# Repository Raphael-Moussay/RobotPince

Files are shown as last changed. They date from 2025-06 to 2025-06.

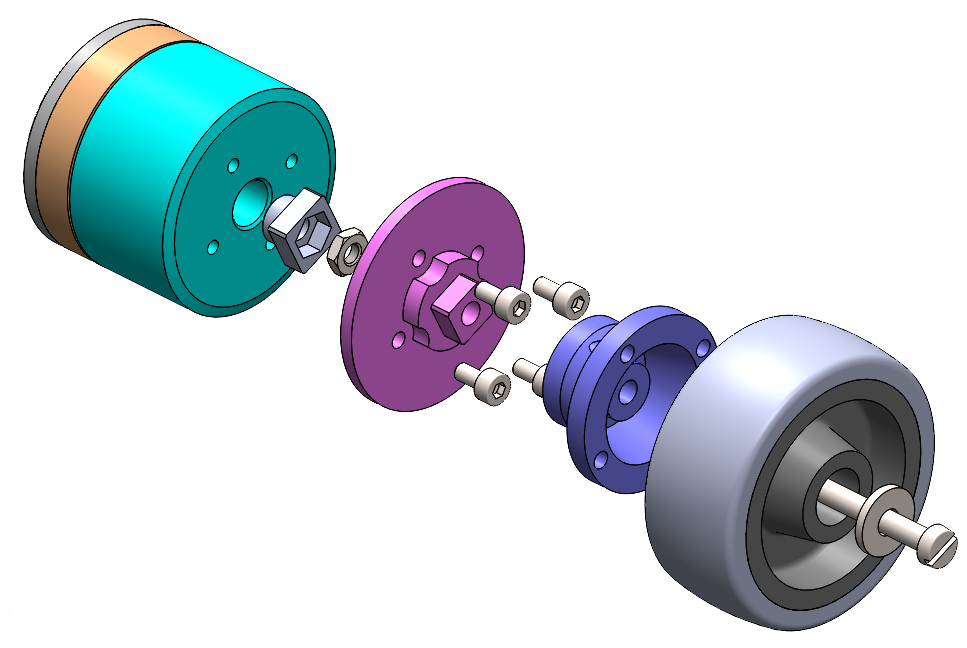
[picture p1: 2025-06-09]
Robot Sous Assemblé/00 composants fournis/moteur MS4015 et roue/montage des roues.png

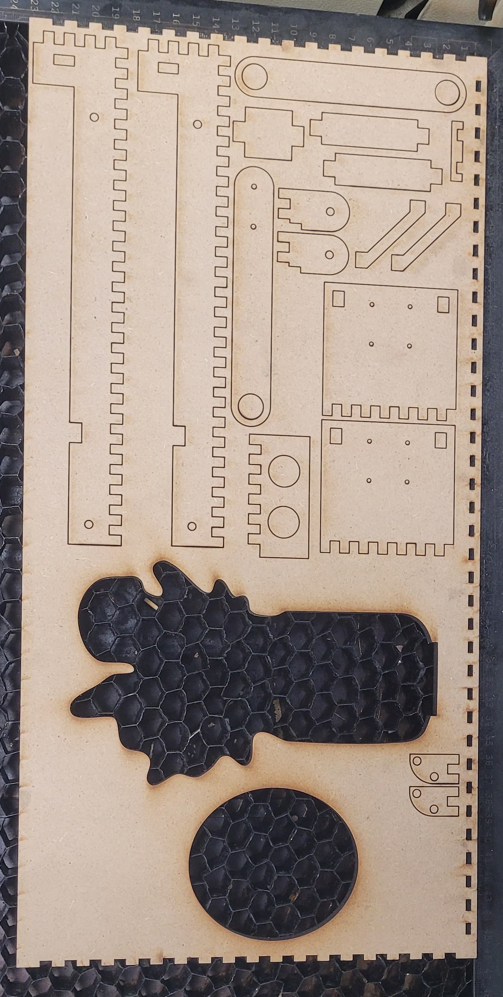
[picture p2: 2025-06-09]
Image découpe laser.jpg

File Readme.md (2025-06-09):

# ROBOPINCEBOT

https://wiki.fablab.sorbonne-universite.fr/BookStack/books/projets-due-2024-2025/page/projet-rob3-gaelle-raphael-sofiane-jean-yves-harold-stanislas

## Description

**ROBOPINCEBOT** est un robot mobile autonome développé dans le cadre du projet de robotique de 3e année à Polytech Sorbonne, spécialité Robotique (février – juin 2025). Le robot est conçu pour localiser, saisir, transporter et déposer un objet dans une arène délimitée à l’aide d’un bras articulé et d’une pince motorisée.

Ce projet a été réalisé au Fablab de Sorbonne Université et mobilise des compétences en mécatronique : conception mécanique (modélisation, usinage), électronique embarquée, programmation sur Arduino et mise en œuvre de capteurs.

## Objectifs

- Concevoir et fabriquer un robot mobile autonome.
- Développer un algorithme de navigation simple par capteurs ultrason.
- Implémenter un système de préhension d’objet via un bras motorisé.
- Réaliser une démonstration fonctionnelle dans un environnement contraint.

## Équipe

| Nom | Email |
|---|---|
| Sofiane BENRABIA | s.benavron@gmail.com |
| Gaelle MARDIKIAN | gaellemardikian29@gmail.com |
| Raphaël MOUSSAY | raphael.moussay@gmail.com |
| Jean ORIEUX | jeanorx@gmail.com |
| Stanislas PINART | stanislas.pinart@gmail.com |
| Yves-Harold VALCIUS  | yvesharoldvalcius11@gmail.com |

## Matériel utilisé

- Carte Arduino UNO
- 3 moteurs MS4015 avec encodeurs
- Bus CAN (MCP2515)
- 2 capteurs à ultrasons HC-SR04
- 1 servomoteur pour la pince
- 1 bouton poussoir
- 2 roues + 1 roue folle
- Batterie
- 2 LabDecks
- Pièces usinées en MDF (laser) via fichiers DXF SolidWorks

## Fonctionnalités

- Déplacement du robot à l’aide de moteurs contrôlés par bus CAN
- Odométrie de position et d’angle
- Détection d’obstacles avec ultrasons (horizontal et vertical)
- Préhension et dépose d’un objet avec une pince articulée
- Démarrage d’une séquence automatisée via bouton poussoir

## Installation

1. **Branchements** : suivre le schéma de câblage dans `https://wiki.fablab.sorbonne-universite.fr/BookStack/books/projets-due-2024-2025/page/projet-rob3-gaelle-raphael-sofiane-jean-yves-harold-stanislas`.
2. **Chargement du code** : ouvrir `Code_Pincebot_final.ino` dans l’IDE Arduino et téléverser sur la carte.
3. **Alimentation** : connecter la batterie.
4. **Démarrage** : appuyer sur le bouton poussoir pour lancer la séquence automatique.

## Dépendances logicielles (Arduino)

- `Servo.h` – contrôle du servomoteur
- `SPI.h` – communication SPI
- `mcp_can.h` / `mcp2515_can.h` – gestion du module CAN MCP2515

## Avancement et journal de bord

Le projet s’est déroulé sur plusieurs mois selon une approche itérative : prototypage, test, ajustement mécanique, implémentation électronique, puis intégration finale.

Les activités hebdomadaires détaillées sont disponibles dans le fichier `Gantt.pdf`.

## Solutions techniques

- **Mobilité** : deux roues arrière motorisées, une roue folle avant
- **Préhension** : pince fixée sur un bras articulé
- **Capteurs** : ultrasons pour éviter les obstacles et mesurer la hauteur de l’objet
- **Commande** : via Arduino et bus CAN, odométrie implémentée par retour encodeur

## Problèmes rencontrés

- Imprécisions des capteurs ultrasons à courte distance
- Stabilité du bras (ajout d’un élastique pour équilibrer le poids)
- Calcul de la position cible pour la dépose (approximation en fonction de l’objet)

## Licence

Ce projet est réalisé à but pédagogique, dans le cadre du cursus ingénieur de Polytech Sorbonne. Toute réutilisation doit être mentionnée comme projet étudiant.

---

*Pour toute question, se référer à la documentation ou contacter l’un des membres de l’équipe.*

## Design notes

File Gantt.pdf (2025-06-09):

GANTT CHART ROB3 Project | Le sujet du projet | Wiki FablabSU (https://wiki.fablab.sorbonne-universite.fr/BookStack/books/projets-due-2024-2025/page/le-sujet-du-projet)
PROJECT TITLE | GANTT CHART ROB3 Project | COMPANY NAME | Les ROBBBB
PROJECT PARTICIPANT | MOUSSAY Raphaël, , ORIEUX Jean, BENRABIA Sofiane, PINART MENUGE Stanislas, MARDIKIAN Gaelle,VALCIUS Yves Harold | DATE | 13/2/2025
Advancement | #REF! | #REF!
TASK TITLE | TASK OWNER | PCT OF TASK COMPLETE | 13/02/2025 | 06/03/2025 | 20/03/2025 | 3/4/2025 | 15/05/2024 | 04/06/2024 DESCRIPTION
CAO (Responsable : Raphael) | | 100,00% | | | | Manifestation devant la fac
Test Découpe laser | Liason entre les plaques, trou pour
les roulements | Raphaël | 100,00%
Modelisation sur Solidworks | Ensemble des pièces | Raphaël | 100,00%
Création des fichiers DXF | Fichier dxf pour chaque pièce à
couper | Raphaël | 100,00%
Découpe laser | Utilisation de la Trotec Speedy
1000 | Raphaël | 100,00%
Montage Robot | Assemblage des pièces | Jean | 100,00%
Dimensionnement | Mesure et calculs pour le bras de la
pince | Stanislas | 100,00%
Equations | Mouvement pour attraper l'objet
quelque soit sa taille | Sofiane | 100%
Bouton poussoir | Découpe et labdeck | Jean
ELECTRONIQUE (Responsable : Gaelle) | | 100,00%
Cablage moteurs +arduino | Code et branchements | Gaëlle | 100,00%
Branchement moteur et bus CAN | Communication entre pince et
arduino | Gaëlle | 100,00%
fonction de la distance récupérée | Gaëlle | 100,00%
Mise en commun codes moteurs et lidar | Commander les moteurs en
Cablage des lidars | Gaëlle | 100,00%
Recharge des batteries | Jean | 100,00%
INFORMATIQUE (Responsable : Yves Harold) | | 100,00%

Test ultrason + Documentation

Savoir ce que renvoit le detecteur, est-ce possible de détecter une hauteur ? l'angle fait entre un objet le robot ? | Harold | 100,00%
Comment faire la liaison moteur <--> arduino ? La fonction de transfert associé avec les bonnes unités ? La conversion de la consigne/commande ? Commande en vitesse ? | Harold | 100,00%

Test moteur + Documentation

Odométrie | Mesure en distance et angle | Harold | 100,00%
Détection des bornes | Changer la vitesse et l'angle à son
| approche | Gaëlle | 100,00%
Saisir l'objet | Hauteur et distance ? | Gaëlle | 100,00%
Relâcher l'objet | Comment le laisser droit au bon endroit ? | Gaëlle | 100,00%
Avance après la balise | | Stanislas | 100,00%
Bouton poussoir | Code | Raphaël | 100,00%
Assembage des fonctions et code complet | | EVERYBODY | 100,00%
Rapport | Sofiane

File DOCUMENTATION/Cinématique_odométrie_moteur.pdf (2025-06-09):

# Cinématique d'un robot mobile de type unicycle

## 1 Introduction et paramétrage

On qualifiera d'unicyle un robot mobile constitué de deux roues motrices indépendantes situées sur le même essieu et d'une roue folle (non motorisée) assurant la stabilité du robot. En supposant le roulement sans glissement des roues sur le sol :

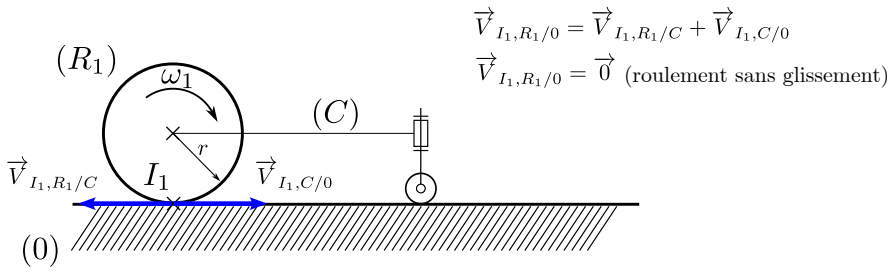
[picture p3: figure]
(roulement sans glissement)
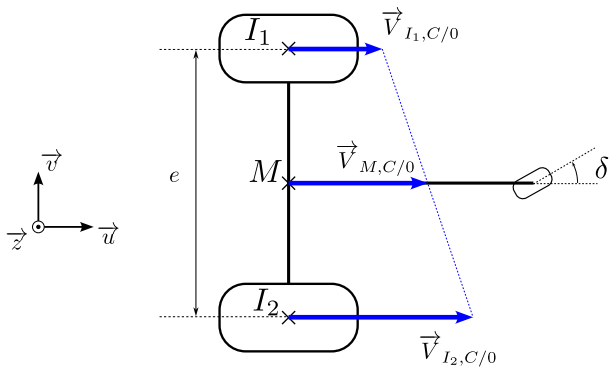
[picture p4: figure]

À tout instant, le centre instantanné de rotation (CIR) du mouvement du chassis par rapport au sol définit le champ des vitesses en rotation. Notons que lorsque les deux moteurs tournent à la même vitesse, le CIR s'éloigne à l'infini et toutes les vitesses sont identiques, c'est une translation. Il est alors possible de déterminer les éléments du torseur cinématique : fVC/Og=(

~
C/0

V~M;C/0 )

M

## 2 Détermination du torseur cinématique du robot en fonction des vitesses angulaires des moteurs

En transportant le torseur respectivement en I1 et I2 : V~

I1;C/0=V~M;C/0+I1M^~

C/0 avec V~
I1;C/0=r!1~u et I1M=¡

e2 ~v

V~

I2;C/0=V~M;C/0+I2M^~

C/0 avec V~
I2;C/0=r!2~u et I2M=

e2 ~v
Par addition : V~

I1;C/0+V~

I2;C/0=2VM;C/0+(I1M+I2M)^~ C/0=2VM;C/0

On obtient : V~M;C/0=

1
2

(V~

I1;C/0+V~
I2;C/0)=

r
2

(!1+!2)~u

1

Par soustraction : V~

I2;C/0¡V~

I1;C/0=I2M^~

C/0¡I1M^~

C/0=e~v^~
C/0
En projection sur ~u : (V~

I2;C/0¡V~

I1;C/0)~u=(e~v^~

C/0)~u=e(~u^~v)~

C/0=e~z~
C/0
On obtient : ~
C/0=

re (!2¡!1)~z

Par commodité, on introduit les notations : V~M;C/0=V~u et ~
C/0=
~z
On peut alors relier les vitesses angulaires des deux roues aux caractéristiques cinématiques du robot (au centre de l'essieu) :

V

=0
@
| r2

r2 ¡

re

re 1
A
!1

!2

forme matricielle qui s'inverse en
!1

!2 =0
@

1
r ¡

e2r 1

r | e2r | 1
A
V

## 3 Répérage et cinématique du robot dans le plan

Pour un repérage du robot dans le plan :

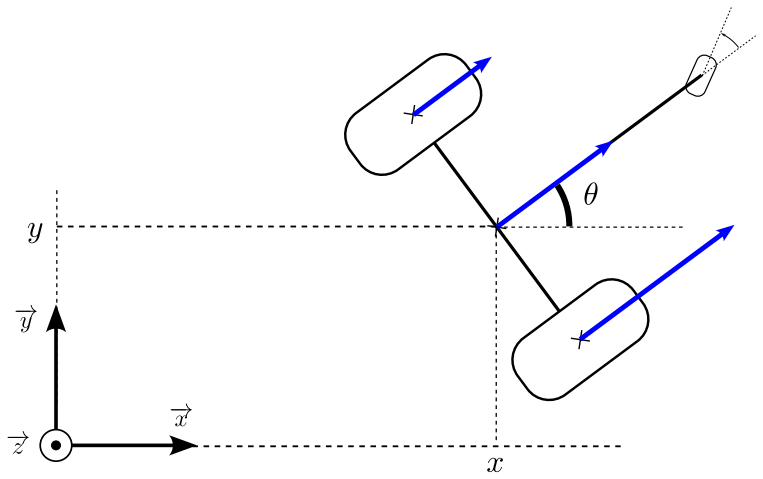
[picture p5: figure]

On définit un vecteur p=0
@

x
y

1
A on peut alors écrire

p_=0
B@

x_y_

_ 1
CA=0
@

V cos
V sin

1

A=0
B
@

r
2

(!1+!2) cos
r
2

(!1+!2)sin
r
e

(!2¡!1)

1
C
A

=0
B
@

r2 cos

r2 cos

r2
sin

r2
sin ¡

re

re 1
C
A
!1

!2

Pour déterminer la vitesse d'un autre point que le centre de l'essieu dans le repère fixe R0, on peut passer par les coordonnées de ce point dans le repère RR au robot. Par exemple, on peut définir un point P tel que MP=a~u. Dans ce cas, la vitesse du point P dans la base mobile est définie par VP /RR=V~u¡a~u^

~z=V~u+a
~v. Le vecteur décrivant les caractéristiques cinématiques au point P dans le repère RR est noté : qR=( V a

)T on cherche q

0=

¡ x_P y_P
_P

T
(dans le repère R0). 2

La vitesse de P dans la base fixe peut alors être déterminée en utilisant la matrice de rotation de la base liée au robot par rapport à la base fixe : R()=0
B@

cos ¡sin 0
sin cos 0
0 | 0 | 1

1
CA

et q

0=R()qR)q

0=0
@

V cos¡a

sin
V sin+a
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
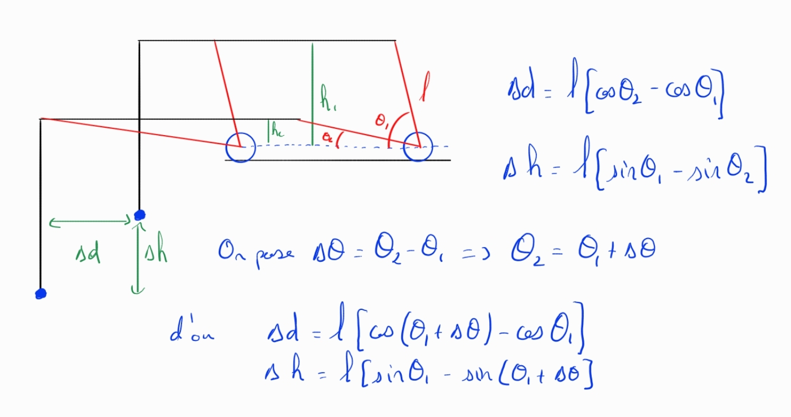
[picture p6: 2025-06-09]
Angle_Distance.jpg

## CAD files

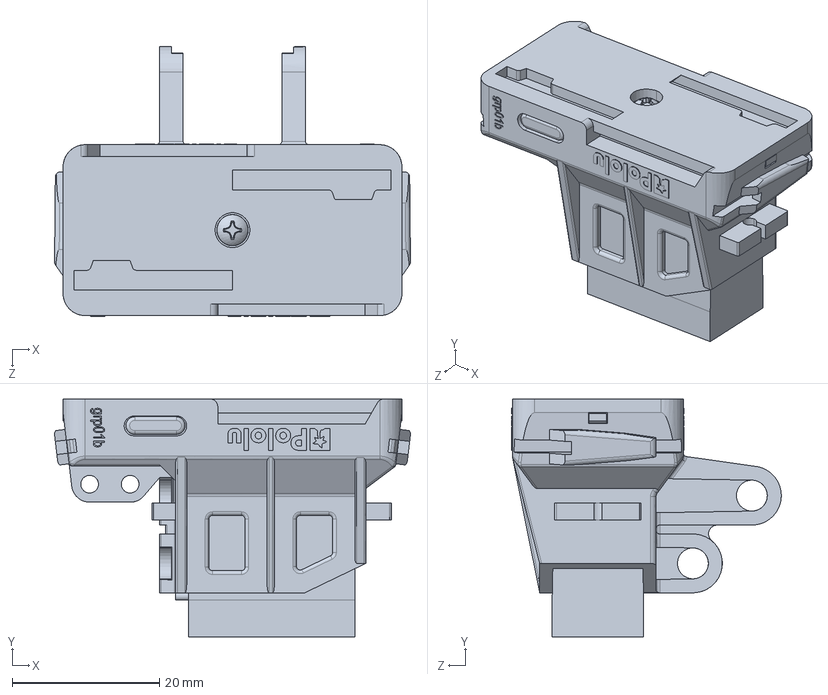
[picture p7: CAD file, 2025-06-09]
Robot Sous Assemblé/00 composants fournis/pince pololu/assembled_gripper_1_1.SLDPRT
48.3 x 32.3 x 36.6 mm

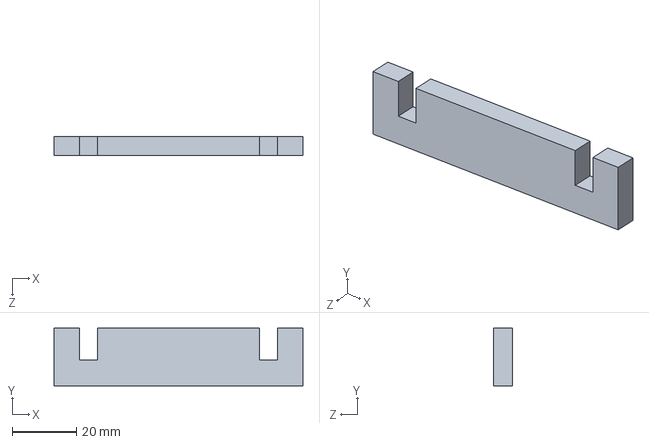
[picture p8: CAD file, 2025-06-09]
Robot Sous Assemblé/Chassis/Maintient ecartement roue arrière.SLDPRT
77.6 x 18.0 x 6.00 mm

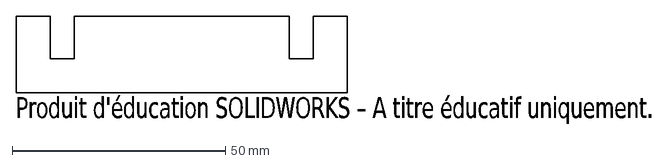
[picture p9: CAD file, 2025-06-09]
Robot Sous Assemblé/DXF/maintient ecartement roue arrière.DXF
Produit d'éducation SOLIDWORKS – A titre éducatif uniquement.

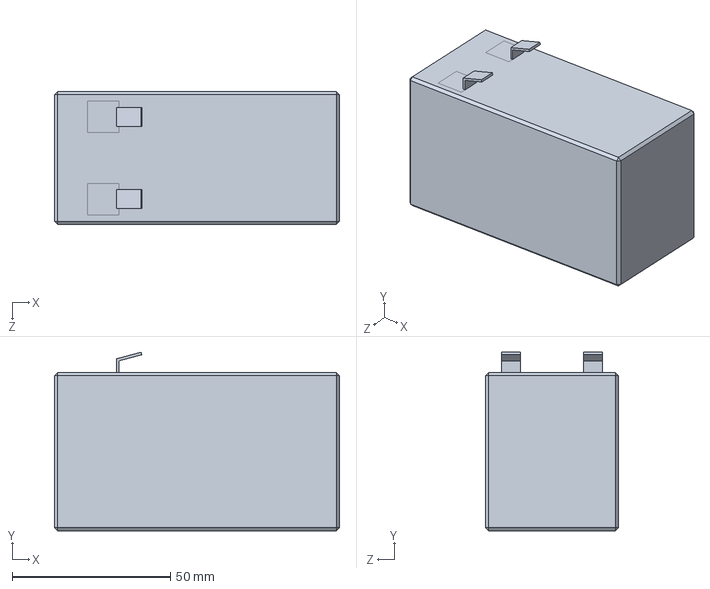
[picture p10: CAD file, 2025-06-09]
Robot Sous Assemblé/00 composants fournis/batterie RS pro 12v/Batterie.SLDPRT
90.0 x 56.4 x 42.0 mm

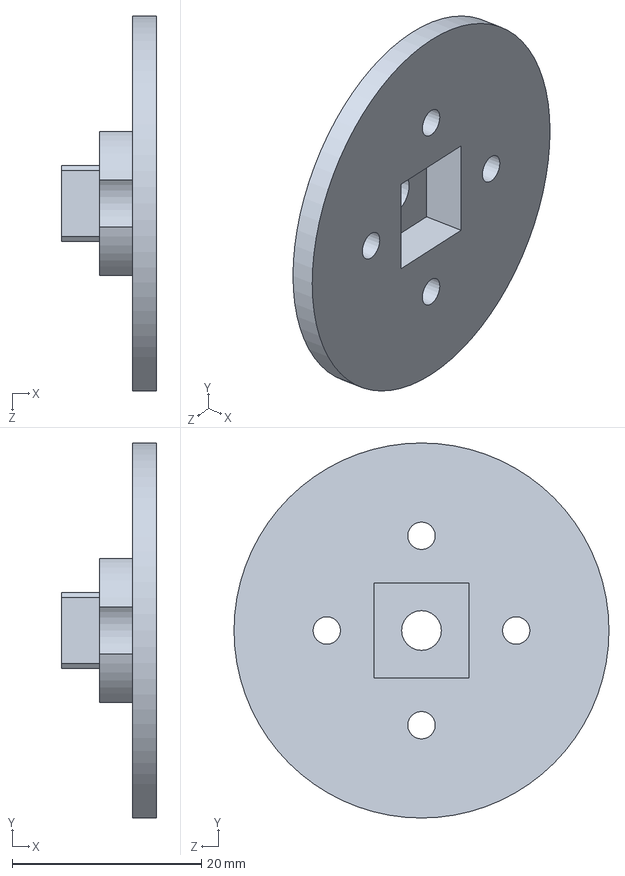
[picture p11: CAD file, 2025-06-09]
Robot Sous Assemblé/00 composants fournis/moteur MS4015 et roue/Entrainement moteur.SLDPRT
10.0 x 39.6 x 39.6 mm

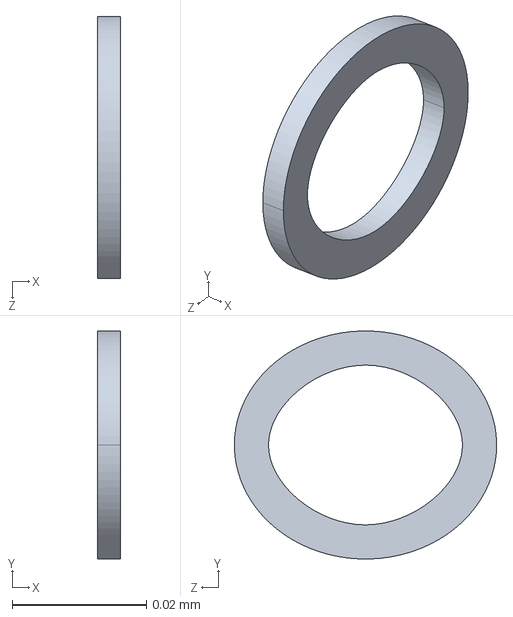
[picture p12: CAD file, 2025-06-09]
Robot Sous Assemblé/00 composants fournis/moteur MS4015/MS4015v21.SLDPRT
0.0034 x 0.034 x 0.0391 mm

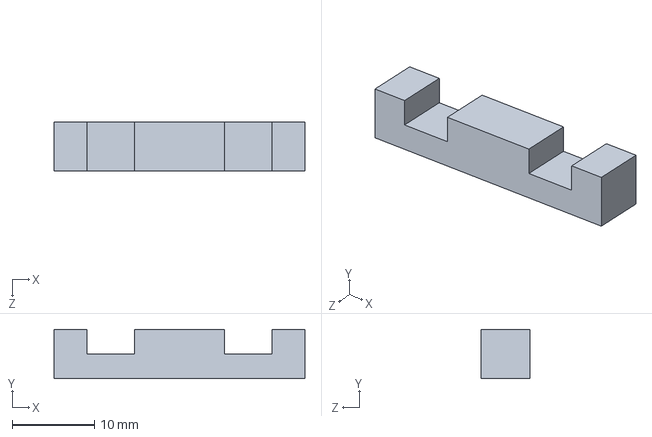
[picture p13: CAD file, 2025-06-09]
Robot Sous Assemblé/Chassis/entretoise Support fourche avant.SLDPRT
30.6 x 6.00 x 6.00 mm

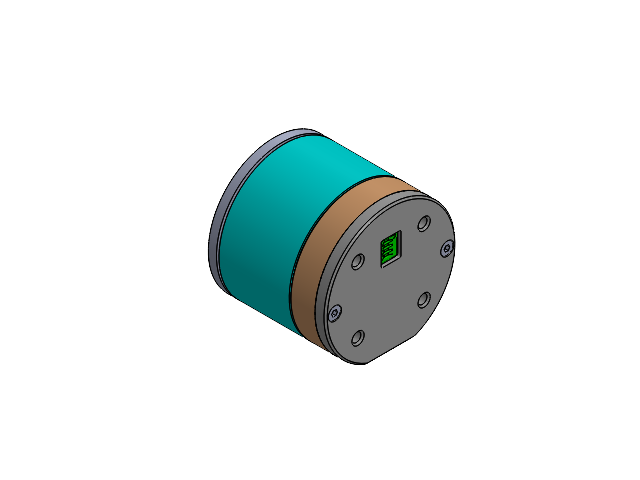
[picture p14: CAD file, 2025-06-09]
Robot Sous Assemblé/00 composants fournis/moteur MS4015 et roue/Moteur équipé.SLDASM
Entrainement moteur
MS4015v21
MS4015v22
MS4015v23
MS4015v24
MS4015v25
MS4015v26
MS4015v27
MS4015v28
MS4015v29
MS4015v210
MS4015v211
MS4015v212
MS4015v213
MS4015v214
MS4015v215
MS4015v216
MS4015v217
MS4015v218
MS4015v219
MS4015v220
MS4015v221
MS4015v222
MS4015v223
MS4015v224
MS4015v225
MS4015v226
MS4015v227
MS4015v228
MS4015v229
MS4015v230
MS4015v231
MS4015v232
MS4015v233
MS4015v234
MS4015v235
MS4015v236
hex thin nut chamfered gradeab_iso
centrage moteur
socket head cap screw_iso x 4

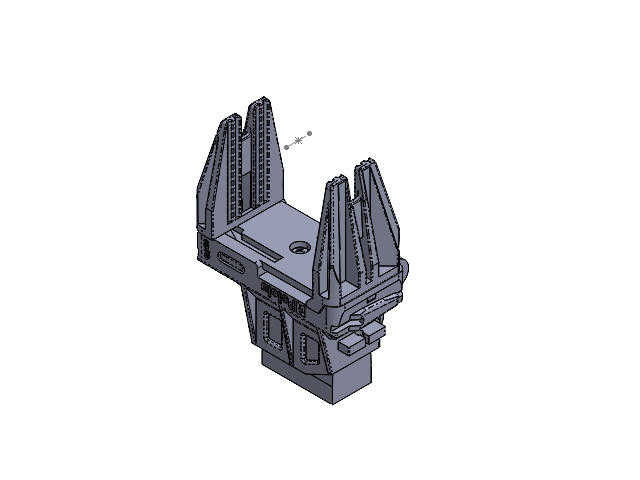
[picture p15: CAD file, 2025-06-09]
Robot Sous Assemblé/00 composants fournis/pince pololu/micro-gripper-3551.SLDASM
assembled_gripper_1_1
grp01c_for_model_1_1 x 2

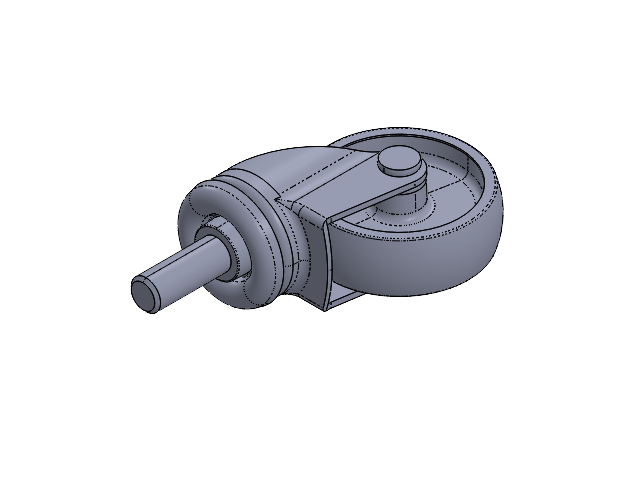
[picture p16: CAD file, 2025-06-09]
Robot Sous Assemblé/00 composants fournis/roue folle/CP1FA050-322L10_.SLDASM
4717051-1-solid1_1
4365163-1-solid1_1
4363551-clienti-1-solid1_1
9070023-1-solid1_1
4115564-1-solid1_1

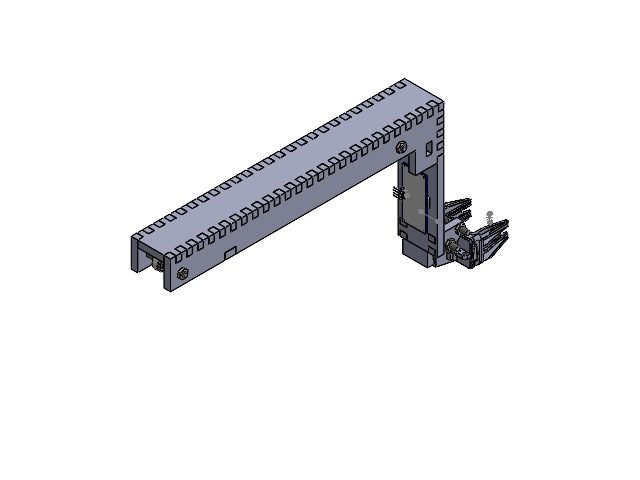
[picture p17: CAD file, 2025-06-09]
Robot Sous Assemblé/Fourche/Fourche.SLDASM
avant fourche
equerre support fourche x 2
planche supérieur support pince
Ultra Sonic Sensor
hex thin nut gradeb_iso x 8
instrument ball bearing_68_iso x 2
socket head cap screw_iso 40 x 4
support pince x 2
assembled_gripper_1_1
grp01c_for_model_1_1 x 2
Entretoise

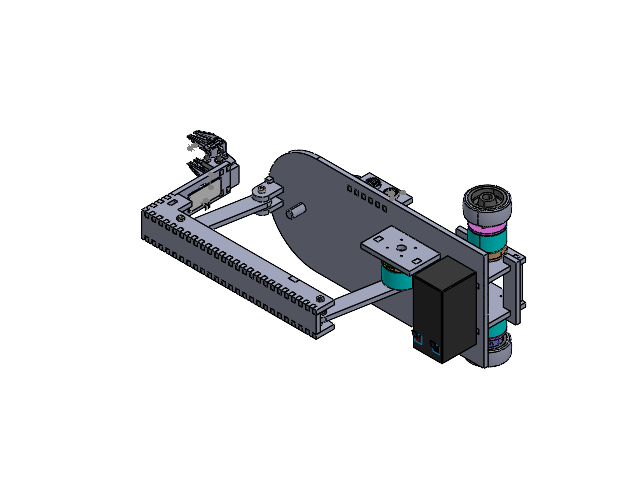
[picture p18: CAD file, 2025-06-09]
Robot Sous Assemblé/ROBOT final.SLDASM
Support moteur Inférieur x 2
Entretoise support moteur inférieur x 2
entretoise Support fourche avant
Support fourche avant x 2
hex thin nut gradeb_iso x 11
socket head cap screw_iso x 9
Support moteur Supérieur
equerre moteur supérieur x 2
Chassis
Batterie
Entrainement moteur x 2
MS4015v21 x 3
MS4015v22 x 3
MS4015v23 x 3
MS4015v24 x 3
MS4015v25 x 3
MS4015v26 x 3
MS4015v27 x 3
MS4015v28 x 3
MS4015v29 x 3
MS4015v210 x 3
MS4015v211 x 3
MS4015v212 x 3
MS4015v213 x 3
MS4015v214 x 3
MS4015v215 x 3
MS4015v216 x 3
MS4015v217 x 3
MS4015v218 x 3
MS4015v219 x 3
MS4015v220 x 3
MS4015v221 x 3
MS4015v222 x 3
MS4015v223 x 3
MS4015v224 x 3
MS4015v225 x 3
MS4015v226 x 3
MS4015v227 x 3
MS4015v228 x 3
MS4015v229 x 3
MS4015v230 x 3
MS4015v231 x 3
MS4015v232 x 3
MS4015v233 x 3
MS4015v234 x 3
MS4015v235 x 3
MS4015v236 x 3
hex thin nut chamfered gradeab_iso x 2
centrage moteur x 2
Copy of Enl_vement de mati_re-R_volution2_1 x 2
Copy of Cong_6_1 x 2
Entrainement roue x 2
Pièce5
4717051-1-solid1_1
4365163-1-solid1_1
4363551-clienti-1-solid1_1
9070023-1-solid1_1
4115564-1-solid1_1
instrument ball bearing_68_iso x 3
support US coté droit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

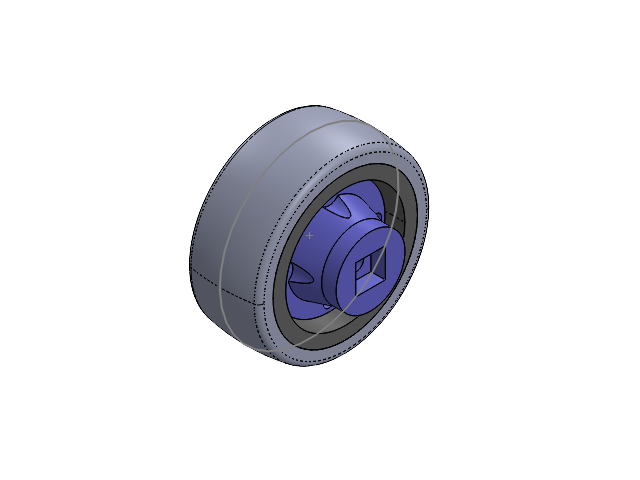
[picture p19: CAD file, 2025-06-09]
Robot Sous Assemblé/00 composants fournis/moteur MS4015 et roue/Roue équipée.SLDASM
Copy of Enl_vement de mati_re-R_volution2_1
Copy of Cong_6_1
Entrainement roue

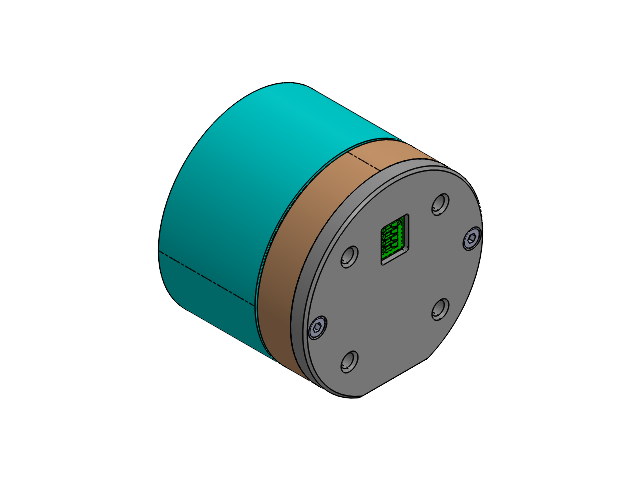
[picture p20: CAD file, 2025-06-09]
Robot Sous Assemblé/00 composants fournis/moteur MS4015 et roue/MS4015v2(2).SLDASM
MS4015v21
MS4015v22
MS4015v23
MS4015v24
MS4015v25
MS4015v26
MS4015v27
MS4015v28
MS4015v29
MS4015v210
MS4015v211
MS4015v212
MS4015v213
MS4015v214
MS4015v215
MS4015v216
MS4015v217
MS4015v218
MS4015v219
MS4015v220
MS4015v221
MS4015v222
MS4015v223
MS4015v224
MS4015v225
MS4015v226
MS4015v227
MS4015v228
MS4015v229
MS4015v230
MS4015v231
MS4015v232
MS4015v233
MS4015v234
MS4015v235
MS4015v236

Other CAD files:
Robot Sous Assemblé/00 composants fournis/moteur MS4015 et roue/325-200-050L10.SLDASM
Robot Sous Assemblé/Chassis/chassis.SLDASM
Robot Sous Assemblé/00 composants fournis/moteur MS4015 et roue/Moteur et Roue.SLDASM
Robot Sous Assemblé/00 composants fournis/moteur MS4015/MS4015v2(2).SLDASM
Robot Sous Assemblé/00 composants fournis/moteur MS4015 et roue/Copy of Cong_6_1.SLDPRT
Robot Sous Assemblé/00 composants fournis/moteur MS4015 et roue/Copy of Enl_vement de mati_re-R_volution2_1.SLDPRT
Robot Sous Assemblé/00 composants fournis/moteur MS4015 et roue/Entrainement roue.SLDPRT
Robot Sous Assemblé/00 composants fournis/moteur MS4015 et roue/MS4015v210.SLDPRT
Robot Sous Assemblé/00 composants fournis/moteur MS4015 et roue/MS4015v211.SLDPRT
Robot Sous Assemblé/00 composants fournis/moteur MS4015 et roue/MS4015v212.SLDPRT
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

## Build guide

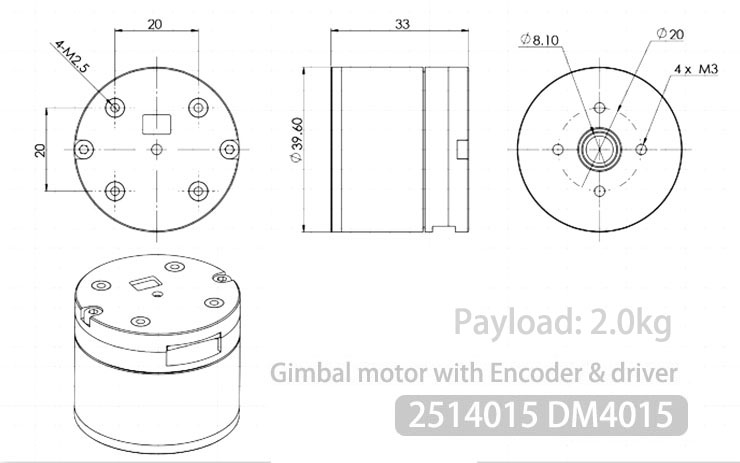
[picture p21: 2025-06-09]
Robot Sous Assemblé/00 composants fournis/moteur MS4015/plan.jpg

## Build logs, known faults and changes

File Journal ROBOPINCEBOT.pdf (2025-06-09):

Projet Rob3 (Gaelle, Raphaël, Sofiane, Jean, Yves-Harold, Stanislas)

NOM Prénom | Email
BENRABIA Sofiane | s.benavron@gmail.com
MARDIKIAN Gaelle | gaellemardikian29@gmail.com
MOUSSAY Raphaël | raphael.moussay@gmail.com
ORIEUX Jean | jeanorx@gmail.com
PINART MENUGE Stanislas | stanislas.pinart@gmail.com
VALCIUS Yves Harold | yvesharoldvalcius11@gmail.com

13/02/2025 | Activités | Problèmes | Prochain Objectifs
Stanislas | Compréhension du fonctionnement de l’ultrason. Mettre un capteur au niveau de l’essieu pour détecter les obstacles, et un au niveau de la pince pour la hauteur.
Raphaël | Aujourd'hui, j'ai créé deux fichiers DXF pour tester la découpe laser. Le premier fichier évalue les diamètres de 12,9 mm, 13 mm et 13,1 mm, tandis que le second teste les diamètres de 12,95 mm, 13,05 mm et 13,15 mm. Les deux fichiers incluent également un système d'assemblage avec des dents rectangulaires qui s'emboîtent pour relier les plaques entre elles. | Aucun soucis à noter | Lors de la prochaine séance, je devrai tester la découpe laser et tester l'ajustement avec les roulements
Gaëlle | Coder et tester le capteur l’ultrason Commencer à comprendre le fonctionnement de la pince (code et branchement) | Imprécision du capteur | Code de la pince
Jean | Recherche de solutions techniques pour le châssis pour répondre aux différents problèmes (hauteur de la roue pivotante trop élevée, position des lidars, etc...) | Toujours pas de solutions viable | Trouver une solution pour le châssis, pince + plateau
Yves Harold | Régler la précision du capteur ultrason Imprécision du capteur : 0.5 cm A quel position, et comment le capteur il capte la distance | Le capteur capte tout droit et augmente un peu la distance mesurée quand y a un angle | Position des capteurs, et code pour capter les bonnes distances
Sofiane | Recherche de solution mécanique pour réaliser le châssis, plus particulièrement la pince. - La pince doit aller assez bas pour attraper l’objet dans le pire cas du très bas. | -Roue folle trop haute -Solution pour la pince: La descendre du bras, le bras aura une forme de Z | Solution pour les roues
GENERAL | | | Finalisez le GANTT + Châssis

06/03/2025 | Activités | Problèmes | Prochains objectifs
Stanislas | Schéma des ensembles roue/moteur. S’assurer de la MIP et de la MAP pour tous les éléments. Mesure des dimensions des composants grâce à solidworks. | Mesurer les pièces précisément sur solidworks | Dimensionner la pince
Raphael | Aujourd’hui, j’ai poursuivi les tests de découpe laser pour ajuster l’encastrement des roulements et des liaisons entre les plaques. Après avoir constaté que le diamètre de 12,9 mm commençait à encastrer, j’ai testé des diamètres de 12,85 mm et 12,8 mm. Le diamètre de 12,85 mm était encore légèrement trop grand, tandis que celui de 12,8 mm a permis un encastrement parfait avec le roulement. Les liaisons entre les planches ont également bien fonctionné avec les dimensions de rectangles choisies (5,2 mm x 4,8 mm). | Mauvaise échelle des pièces découpés lors de l'utilisation d’Inscape | Modéliser le châssis
Gaëlle | Réaliser la communication entre la pince et Arduino. Branchement du moteur avec le bus CAN | Assemblage de la pince compliqué pour avoir une rotation cohérente | Code pour commander le moteur
Jean | Schéma du châssis, du bras et des pivots, ainsi que la pince et le capteur au bout du bras. Début des mesures de chaque pièces Résolution des problèmes de la semaine dernière concernant les solutions de la pince et de la forme du châssis | Mauvais schéma de la roue et du pivot châssis/pince | Dimensionnement du châssis et de la pince pour modélisation
Yves-Harold | Structure de code pour commander le moteur, Communication du CAN avec le moteur. | Problème code pour faire tourner les moteurs | Faire tourner les moteurs un à un et ensuite indépendamment

13/03/2025 | Activités | Problèmes | Prochain Objectifs
Stanislas | J’ai calculé à partir d’inconnues, les dimensions du bras qui porte la pince et un lidar, les barres qui pivotent . | Inconnues au lieu de scalaires

20/03/2025 | Activités | Problèmes | Prochain Objectifs
Stanislas | Réglage des derniers problèmes de dimensionnement de la pince. Schématisation finales | Largeur de la pince vis à vis de la largeur du bras → Écart de 6 mm et résolu en écartant le bras avec deux pièces rallonges | Assemblage des pièces du robot
Raphaël | Modélisation du châssis à partir des schémas. Test d’usinage des encastrements pour les détecteurs de distance -> Diamètre d’usinage 16 mm | Problème de taille d’encastrement → Résolu avec 2/10 de millimètres | finaliser la modelisation de ttes les pièces
Gaëlle | Mise en commun des codes moteurs et des détecteurs de distance pour commander les moteurs en fonction des distances récupérées. | Problème avec la communication arduino | Finir l’algorithme reliant distance et moteurs
Jean | Assemblage des roues sur leur support et les moteurs. Finalisation des problèmes liés au dimensionnement des fixation moteurs. | Taille de trous pour les vis→ perçage | Recherche et mise en place de l’odométrie
Yves Harold | Créer les fonctions de déplacement en changeant les consignes moteurs. Indépendance des moteurs en fonction des ID. | Création des tableaux en fonction des ID. Fonction loop() mal géré pour stopper les moteurs | Finir commande des moteurs en vitesse et en position
Sofiane | Mécanique: ➔ dimensions du bras de robot pour qu’il puisse attraper l’objet minimum quand l’angle du bras est de 20° et attraper l’objet de taille max quand l’angle est de 50°. | l’équation du mvt en translation dépend de l’angle du bas au lieu de la vitesse | Finir l’équation du mvt en translation.

| ➔ équation du mouvement pour que face à l’objet la pince ait un mouvement de translation rectiligne parallèle au sol. Algorithme: ➔ algorithme du déplacement du robot dans l’arène. Le robot doit pouvoir se déplacer simplement jusqu’à l’objet puis jusqu’à la zone de dépôt. | du moteur, et donne la valeur d’une longueur clé mais pas du déplacement nécéssaire

GENERAL

18/04/2025 | Activités | Problèmes | Prochain Objectifs
Raphaël | Modélisation de toute les pièces création des sous assemblages et le l’assemblage finale sur Solidworks | | Découpe laser des pièces et assemblage du robot
14/05/2025 | Activités | Problèmes | Prochain Objectifs
Raphaël | Transformation de toutes les pièces en format DXF et découpe laser des pièces. Assemblage du robot

Jean
Découpe au laser des pièces, Assemblage du robot
15/05/2025 | Activités | Problèmes | Prochain Objectifs
Stanislas | Amélioration du Gant. Formule du temps de rotation pour obtenir l’angle du bras du robot, pour le code arduino.
Raphaël | Finaliser la modélisation des pièces supplémentaires (Crochet pour moteurs), mise en place des différentes pièces sur le robot Perçage et collage de certains emboîtement pour faciliter le montage | | Sans doute faire un contrepoids finalisation montage bras avant
Gaëlle | Coder le moteur du bras du robot spécifiquement la limite d’angle | | Finir le code pour bras pince
Jean | Mise en page du rapport avec dessin et schéma. Mise en place des différentes pièces sur le robot | | Le rapport
Yves Harold | Bonne lecture de l'état des moteurs et odométrie. | | finaliser l’odométrie pour commander en angle ou en

| | distance.
Sofiane | Travail sur le rapport, mise en page. Théorie angle distance pour la pince

GENERAL

28/05/2025 | Activités | Problèmes | Prochain Objectifs

Stanislas

Raphaël | Mise en place de l’élastique pour compenser le poids du bras

Gaëlle

Jean

Yves Harold

Sofiane

GENERAL

04/065/2025 | Activités | Problèmes | Prochain Objectifs

Stanislas

Raphaël | Cable managment +bouton sur l’alimentation

Gaëlle

Jean

Yves Harold

Sofiane

GENERAL

05/06/2025 | Activités | Problèmes | Prochain Objectifs

Stanislas

Raphaël | Refonte du code
Gaëlle | Refonte du code
Jean | Refonte du code

Yves Harold

Sofiane

GENERAL

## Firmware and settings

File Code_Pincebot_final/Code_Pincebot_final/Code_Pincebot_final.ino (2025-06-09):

/*/
/****** AUTOMATIC CONTROL - POLYTECH SORBONNE - JAN 2025 ****/
/******** AUTHORS : L. BRIETZKE & G. MOREL *******/
/********* Sequence 1 - Problem 1 **********/
/********** YOU'RE IN CONTROL **********/


// Libraries for CAN communications
#include <Servo.h>
#include <can-serial.h>
#include <mcp2515_can.h>
#include <mcp2515_can_dfs.h>
#include <mcp_can.h>
#if defined(SEEED_WIO_TERMINAL) && defined(CAN_2518FD)
const int SPI_CS_PIN = BCM8;
const int CAN_INT_PIN = BCM25;
#else
const int SPI_CS_PIN = 10;
const int CAN_INT_PIN = 2;
#endif

#include "mcp2515_can.h"
mcp2515_can CAN(SPI_CS_PIN);  // Set CS pin
#define MAX_DATA_SIZE 8

#include <SPI.h>
#include <math.h>

#define MY_PI 3.14159265359

#define PERIOD_IN_MICROS 25000 // 5 ms

// Identifiants des moteurs (en hexadécimal)
#define MOTOR_1_ID 0x01
#define MOTOR_2_ID 0x02  //moteur droite, vitesse negative pour avancer
#define MOTOR_3_ID 0x03  //  moteur gauche, vitesse positive pour avancer. 


/********* Variables globales. *********/
double relativeMotorPosEncoder[3]={0.0,0.0,0.0};

int offsetMotorPosEncoder[3] = {0,0,0}; // Offset de la position de l'encodeur
int currentNumOfMotorRevol[3]= {0,0,0}; // Nombre actuel de révolutions du moteur
double previousMotorPosDeg[3] ={0.0,0.0,0.0}; // Position précédente du moteur en degrés

// Tableaux pour stocker la vitesse et la position des moteurs
double currentMotorVelDegPerSec[3] = {0.0, 0.0, 0.0}; // Vitesse en degrés par seconde
double currentMotorPosDeg[3] = {0.0, 0.0, 0.0}; // Position en degrés
double currentMotorPosEncoder[3]= {0.0, 0.0, 0.0};
double currentMotorVelRaw[3] = {0.0, 0.0, 0.0};

// ==== Variables d'odométrie ====
double x = 0.0, y = 0.0, theta = 0.0;                // pose en mm et rad
const double Diametre_Roue_MM = 49.5;               // diamètre / mm
const double Dist_Roue_MM     = 177.0;               // entraxe roues / mm

// mémorisation des positions précédentes (en degrés) des deux roues
double prevMotorPosL = 0.0;  // pour MOTOR_3_ID (roue gauche)
double prevMotorPosR = 0.0;  // pour MOTOR_2_ID (roue droite)

// ——— En haut du fichier, avec tes autres constantes ———
const int SIGNE_MOTOR2 = -1;  // Moteur 2 = roue droite, signe – pour avancer
const int SIGNE_MOTOR3 = +1;  // Moteur 3 = roue gauche, signe + pour avancer

const int pin_trigavant = 4;
const int pin_echoavant = 3;

const int pin_led = 13;
const int pin_bouton = 2;
int run=0;
bool last_bouton = HIGH;

long duration=0;
float distanceCM=0;
float distancecoteCM=0;

// balise trouve
float prev_distanceCM=0;
float prev_distancecoteCM=0;
int chrono=0;
int chronoMIN=0;
int min=30000;


const int pin_trigcote = 7;
const int pin_echocote = 6;


const int pin_pince = 5;

int etat=0;
int temp_distancecote=0;

int gripperPos = 0;     
int feedbackVal = 0;   

int i=0;

float distance_cible = 0;


Servo servopince;

int vitesse=20000;
/********* Commandes moteur *********/

// Allumer un moteur
void motorON(uint8_t motor_id) {
  unsigned char msg[MAX_DATA_SIZE] = {0x88, 0, 0, 0, 0, 0, 0, 0};
  CAN.sendMsgBuf(0x140 + motor_id, 0, 8, msg);
}

// Éteindre un moteur
void motorOFF(uint8_t motor_id) {
  unsigned char msg[MAX_DATA_SIZE] = {0x80, 0, 0, 0, 0, 0, 0, 0};
  CAN.sendMsgBuf(0x140 + motor_id, 0, 8, msg);
}

void sendVelocityCommand(uint8_t motor_id, long int vel) {

  long int local_velocity;
  local_velocity = vel;

  unsigned char *adresse_low = (unsigned char *)(&local_velocity);

  unsigned char msg[MAX_DATA_SIZE] = {
    0xA2,
    0x00,
    0x00,
    0x00,
    *(adresse_low),
    *(adresse_low + 1),
    *(adresse_low + 2),
    *(adresse_low + 3)
  };

  CAN.sendMsgBuf(0x140 + motor_id, 0, 8, msg); 
}

int readMotorState(int motorID) {
    /*
    Récupère l'état du moteur identifié via les mesures de l'encodeur, et met à jour la valeur des variables globales suivantes :
    - currentNumOfMotorRevol : Nombre de révolutions du moteur (valeur précédente +/- 1 selon si une révolution à été observé par l'encodeur)
    - currentArmMotorPosDeg : Position du moteur en degrés, calculée à partir des valeurs brutes de l'encodeur
    - current(Left/Right/Arm)MotorVel : Vitesse du moteur, en degrés par secondes
    - previousArmMotorPosDeg : Position actuelle, en degrés (car la position actuelle deviendra la précédente au prochain appel)
    */
  
    uint32_t id;
    uint8_t type;
    uint8_t len;
    byte cdata[MAX_DATA_SIZE] = {0}; // Déclare et remplit le tableau de 0, buffer utilisé pour receptionner les données
    int data2_3, data4_5, data6_7;
    int rawMotorVel;
    int absoluteMotorPosEncoder;

    int timeout=0;

    // Attend de réceptionner des données
    while (CAN_MSGAVAIL != CAN.checkReceive() && timeout < 5000) {
      delayMicroseconds(1000);
      timeout++;
    }
    if (timeout > 5000) return -1;
    // Lis les données, len: data length, buf: data buf
    CAN.readMsgBuf(&len, cdata); // Écrit les valeurs du message transmis par le bus (données) CAN dans le buffer cdata
    id = CAN.getCanId(); // Récupère la valeur de l'ID du bus CAN depuis lequel les données sont reçues
    type = (CAN.isExtendedFrame() << 0) | (CAN.isRemoteRequest() << 1);


    if ((id - 0x140) == motorID) { // Si l'ID reçu correspond à celui du moteur
      data4_5 = cdata[4] + 256 * cdata[5];
      rawMotorVel = (int)data4_5; // Calcul la vitesse brute
      data6_7 = cdata[6] + 256 * cdata[7];
      absoluteMotorPosEncoder = (int)data6_7;
    }
  
    // Convertit la vitesse brute en degrés par secondes
    currentMotorVelDegPerSec[motorID - 1] = (double)rawMotorVel;
    
    relativeMotorPosEncoder[motorID - 1] = (double)absoluteMotorPosEncoder;
  
    // Déduction de la position en degré à partir de l'offset, du nombre de révolutions, et de la valeur brute en unité encodeur
    relativeMotorPosEncoder[motorID - 1] -= offsetMotorPosEncoder[motorID - 1]; // On adapte la position en fonction du décalage introduit initialement (position de départ)
    currentMotorPosDeg[motorID - 1] = 180.0 + ((double)relativeMotorPosEncoder[motorID - 1]) * (180.0 / 32768.0);  // Met à jour la variable globale
  
    double delta = currentMotorPosDeg[motorID - 1] - previousMotorPosDeg[motorID - 1];
    if (delta > 180.0) {
        currentNumOfMotorRevol[motorID - 1]--;
    } else if (delta < -180.0) {
        currentNumOfMotorRevol[motorID - 1]++;
    }
  
    // Affecte à la position précédente la valeur de la position courante pour le prochain appel
    previousMotorPosDeg[motorID - 1] = currentMotorPosDeg[motorID - 1]; // writing in the global variable for next call

    return 0;
}

/********* Initialisation *********/

void setup() {



  pinMode(pin_trigavant, OUTPUT); 
  pinMode(pin_echoavant, INPUT);
  pinMode(pin_trigcote, OUTPUT); 
  pinMode(pin_echocote, INPUT);
  
  //Bouton poussoir
  pinMode(pin_bouton,INPUT);
  pinMode(pin_led,OUTPUT);

  Serial.begin(115200);
  delay(1000);
  servopince.attach(pin_pince);  
  while (CAN_OK != CAN.begin(CAN_500KBPS)) {
    Serial.println("CAN init fail, retry...");
    delay(500);
  }

  Serial.println("\n=== Initialisation CAN OK ===");

 
  // Initialisation des trois moteurs
  motorOFF(MOTOR_1_ID);  // Éteindre moteur 1
  delay(500);
  motorON(MOTOR_1_ID);   // Allumer moteur 1
  delay(500);

  motorOFF(MOTOR_2_ID);  // Éteindre moteur 2
  delay(500);
  motorON(MOTOR_2_ID);   // Allumer moteur 2
  delay(500);

  motorOFF(MOTOR_3_ID);  // Éteindre moteur 3
  delay(500);
  motorON(MOTOR_3_ID);   // Allumer moteur 3
  delay(500);

  //Démarrage à vitesse nulle pour sécurité
  velocity(MOTOR_1_ID, 0);

  velocity(MOTOR_2_ID, 0);

  velocity(MOTOR_3_ID, 0);


   // 2) Stocker ces positions comme références « prev »
  prevMotorPosL = currentMotorPosDeg[MOTOR_3_ID - 1];
  prevMotorPosR = currentMotorPosDeg[MOTOR_2_ID - 1];


  Serial.println("=== Odometrie initialisé ===");

  Serial.println("=== Tous les moteurs prêts ===");


}

void velocity(uint8_t motor_id, long int vel){
    sendVelocityCommand(motor_id,vel);
    readMotorState(motor_id);
}

void capteur_avant(){
  digitalWrite(pin_trigavant, LOW);
  delayMicroseconds(2);
  digitalWrite(pin_trigavant, HIGH);
  delayMicroseconds(10);
  digitalWrite(pin_trigavant, LOW);

  // Lecture de la durée de l'impulsion ECHO
  duration = pulseIn(pin_echoavant, HIGH, 10000);

  // Calcul de la distance (vitesse du son ≈ 343 m/s)
  distanceCM = (duration * 0.0343) / 2;

  // Affichage de la distance
  // Serial.print("Distance: ");
  // Serial.print(distanceCM);
  // Serial.println(" cm");


}

void capteur_cote(){
  digitalWrite(pin_trigcote, LOW);
  delayMicroseconds(2);
  digitalWrite(pin_trigcote, HIGH);
  delayMicroseconds(10);
  digitalWrite(pin_trigcote, LOW);


  duration = pulseIn(pin_echocote, HIGH, 10000);


  distancecoteCM = (duration * 0.0343) / 2;

  // Serial.print("Distance cote: ");
  // Serial.print(distancecoteCM);
  // Serial.println(" cm"); 
}

void ouvrir_la_pince(){
  servopince.write(0);  
  // Serial.print("0 degrées: "); //Pince ouverte
  delay(1000);
  // Serial.println(analogRead(A0));
}

void fermer_la_pince(){
  servopince.write(120);  
  // Serial.print("180 degrées: "); //Pince ouverte
  delay(1000);
  // Serial.println(analogRead(A0));
}

void avancer(){
  velocity(MOTOR_2_ID, SIGNE_MOTOR2*vitesse);
  velocity(MOTOR_3_ID, SIGNE_MOTOR3*vitesse);
}

void reculer(){
  velocity(MOTOR_2_ID, -SIGNE_MOTOR2*vitesse);
  velocity(MOTOR_3_ID, -SIGNE_MOTOR3*vitesse);
}

void stop1(){
  velocity(MOTOR_1_ID,0);
}

void stop(){
  velocity(MOTOR_3_ID,0);
  velocity(MOTOR_2_ID,0);
}

void tourner_90_gauche(){

  velocity(MOTOR_2_ID, SIGNE_MOTOR2*vitesse);
  velocity(MOTOR_3_ID, -SIGNE_MOTOR3*vitesse);
  delay(1400);// delay pour tourner de 90
  // delay(1400);// delay pour tourner de 70
  stop();
}

void attraper(){
  stop();
  stop1();
  ouvrir_la_pince();
  //reculer
  reculer();
  //delay et stop
  delay(1000);
  stop();
  stop1();
  velocity(MOTOR_1_ID,vitesse);
  delay(2000);
  fermer_la_pince();
  delay(50);
  velocity(MOTOR_1_ID,-vitesse);
  delay(2000);
}

void descendre_la_pince(){
  velocity(MOTOR_1_ID,-vitesse);
  delay(1000);
}

bool balise_trouve_cote (){
  capteur_cote();
  if (abs(prev_distancecoteCM-distancecoteCM) > 10) {
    Serial.println("Balise trouve cote");
    return true;
  } else {
    return false;
  }
}

void avancer_mur() {
  prev_distancecoteCM = distancecoteCM;  // sauvegarde de la distance précédente
  capteur_cote();  // met à jour distancecoteCM
  
  float erreur = distancecoteCM - distance_cible;

  // Gain proportionnel — ajuste-le pour des résultats plus ou moins agressifs
  float Kp = 100.0;

  // Calcul correction
  int correction = Kp * erreur;

  // Saturation pour ne pas dépasser les valeurs admissibles
  correction = constrain(correction, -20000, 20000);

  // Vitesse de base
  int base_speed = 20000;

  // Ajustement moteur (en supposant que M2 est gauche, M3 est droite)
  velocity(MOTOR_2_ID, SIGNE_MOTOR2 * (base_speed - correction));
  velocity(MOTOR_3_ID, SIGNE_MOTOR3 * (base_speed + correction));

  if(prev_distancecoteCM!=0 && distancecoteCM!=0){
    float ecart = distancecoteCM - prev_distancecoteCM;
    if (ecart > 7 && (etat==1 || etat==8 || etat==10)) {
      etat=etat+1;
      Serial.println("Balise détectée !");
    }
  }

}


bool balise_trouve_avant (){
  prev_distanceCM = distanceCM;
  capteur_avant();
  if (distanceCM < 10) {
    Serial.println("Balise trouve avant");
    return true;
  } else {
    return false;
  }
}

void bras_position(float consigne_pos_bras){
  // readMotorState(MOTOR_1_ID);
  float epsilon = 3;
  float erreur = currentMotorPosDeg[MOTOR_1_ID-1] - consigne_pos_bras;
  if(erreur>epsilon) 
  {
    velocity(MOTOR_1_ID,-vitesse);
  }else if(erreur<(-epsilon)){
    velocity(MOTOR_1_ID,vitesse);
  }
}

int balayage() {
    velocity(MOTOR_2_ID, SIGNE_MOTOR2*1000);
    delay(5);
    prev_distanceCM = distanceCM;
    capteur_avant();
    // Serial.print("prev_distanceCM");
    // Serial.println(prev_distanceCM);
    // Serial.print("distanceCM");
    // Serial.println(distanceCM);
    if(prev_distanceCM!=0 && distanceCM!=0){
      float ecart = abs(prev_distanceCM-distanceCM);
      if(ecart>20){
        return true;
      }else{
        return false;
      }
    }else{
      return false;
    }
    // chrono+=5;
    // capteur_avant();
    // if (distanceCM<min && distanceCM>1)
    // {
    //   min=distanceCM;
    //   chronoMIN=chrono;
    // }
  }
  // velocity(MOTOR_2_ID, -SIGNE_MOTOR2*5000);
  // delay(3000-chronoMIN);
  // stop();


int capteur_1fois=0;

void attrape_objet_petit(){
  Serial.println("attrape");
  stop();

  //remonte et ouvre la pince
  ouvrir_la_pince();
  sendVelocityCommand(MOTOR_1_ID, -vitesse-10000);
  delay(385);//remonte

  //avance attrape et remonte
  stop1();
  avancer();
  delay(1400); 
  stop();
  fermer_la_pince();
  Serial.print("Pince ferme");
  sendVelocityCommand(MOTOR_1_ID, vitesse+20000);
  delay(5000);
}

void ungrab(){
  sendVelocityCommand(MOTOR_1_ID, vitesse);
  delay(100);
  stop();
  ouvrir_la_pince();
  reculer();
  delay(1000);
  stop();
}

void loop() {
  int etat_bouton = digitalRead(pin_bouton);
  // Serial.println(etat_bouton);
  
  if ((etat_bouton == HIGH) && (last_bouton == LOW)) {
    etat = (etat == 0) ? 1 : 0;
    Serial.println("Changement d'état !");
    delay(50); // anti-rebond
    digitalWrite(pin_led,HIGH);
    capteur_cote();
    distance_cible = distancecoteCM;
    Serial.println(distanceCM);
  }else{
    digitalWrite(pin_led,LOW);
  }
  
  last_bouton = etat_bouton;
  // if(etat==1){
  //   if(balayage()){
  //       delay(100);
  //         stop();
  //         etat=0;
  //   }
  // }
  switch (etat) {
    case 0 :
      stop();
      stop1();
      prev_distanceCM = distanceCM;
      prev_distancecoteCM = distancecoteCM;
      capteur_avant();
      capteur_cote();
      Serial.println(distancecoteCM);
      break;
    case 1 :

  //   attrape_objet_petit();
  //     stop();
  //     stop1();
  //     tourner_90_gauche();
  //     etat = etat+1;
  //     break;
  // }

      avancer_mur();
      break;
    case 2 :
      avancer();
      delay(1300);
      tourner_90_gauche();
      stop();
      avancer();
      delay(800);
      stop();
      etat = 3;
      break;
    case 3 :
      velocity(MOTOR_1_ID,20000);
      delay(3000);
      etat=4;
      break;
    case 4 : 
      capteur_avant();
      prev_distanceCM = distanceCM;
      if(balayage()){
        velocity(MOTOR_2_ID, SIGNE_MOTOR2*1000);
        delay(1450);
        stop();
        etat=5;
      }
      break;
    case 5 :  
      avancer();
      if (balise_trouve_avant())
      {
        stop();
        delay(2000);
        etat=6;
      }
      break;
    case 6 :  
      attrape_objet_petit();
      stop();
      stop1();
      etat=etat+1;
      break;
    case 7 :
      avancer();
      delay(1200);
      stop();
      velocity(MOTOR_2_ID, SIGNE_MOTOR2*vitesse);
      velocity(MOTOR_3_ID, -SIGNE_MOTOR3*vitesse);
      delay(1600);// delay pour tourner de 90
      // delay(1400);// delay pour tourner de 70
      stop();
      delay(500);
      capteur_cote();
      distance_cible = distancecoteCM;
      etat= etat+1;
      break;
    case 8 :
      avancer_mur();
      break;
    case 9 :
      stop();
      avancer();
      delay(1200);
      stop();
      velocity(MOTOR_2_ID, SIGNE_MOTOR2*vitesse);
      velocity(MOTOR_3_ID, -SIGNE_MOTOR3*vitesse);
      delay(1600);// delay pour tourner de 90
      stop();
      delay(500);
      capteur_cote();
      distance_cible = distancecoteCM;
      etat=etat+1;
      break;
    case 10 : 
      avancer_mur();
      break;
    case 11 : 
      stop();
      reculer();
      delay(2000);
      ungrab();
      etat=etat+1;
      break;
    case 12:
      stop();
      break;
  }

  
}
